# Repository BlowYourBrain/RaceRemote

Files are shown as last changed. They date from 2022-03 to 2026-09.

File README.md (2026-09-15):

# RaceRemote

Текущая сборка: [плата 0.3, отдельный общий провод XIAO и карта подключений](cad/xiao-return-h10/README.md).

Последняя примерка: [провода мотора и обнаруженный конфликт резерва клеммы с подвеской](cad/motor-harness/README.md).

Текущий вариант внутреннего питания: [CAD припаянной пары и крепления](cad/direct-logic-harness/README.md), включая ограничения прежней проводки.

Проект одинаковых радиоуправляемых машинок с управлением по Wi-Fi с телефона, сменными кузовами и опциональной камерой.

**Перед продолжением работы прочитайте [описание проекта и принятые решения](docs/project-brief.md).** Там собраны требования, имеющееся железо, результаты первичного аудита и вопросы, которые ещё предстоит решить.

**Ближайшие шаги к физической сборке:** [первый прототип](docs/first-prototype.md) — доступные устройства, недостающие данные и порядок радио/FPV, привода, механики и зарядки.

- [Стенд Android ↔ ESP32](docs/control-bench.md) — `vea.raceremote`, запуск и проверенные устройства.
- [Протокол Control v1](docs/control-v1.md) — команды, сессия и остановка.
- [Подготовка стенда привода](docs/drive-bench.md) — проект соединений TA6586, питание и проверка рулевого узла.
- [Контракты и их статус](docs/contracts.md) — согласованные требования и интерфейсы, которые предстоит определить.
- [Архитектура и known unknowns](docs/architecture-and-unknowns.md) — организация системы, открытые вопросы и способы их закрыть.
- [Кандидаты шасси](docs/chassis-candidates.md) — исходные проекты, ограничения и возможная адаптация под Wi-Fi.
- [Детали и цены](docs/parts.md) — предложения магазинов, количество на 1/4/6 машинок и незакрытые позиции.
- [Камера для FPV](docs/camera-candidates.md) — кандидаты и проверка задержки до выбора для серии.
- [Первый FPV-стенд](docs/fpv-bench.md) — состав, подключение и порядок измерений; предложение для покупки ещё подбирается.
- [USB-C: зарядка и прошивка](docs/usb-c-power.md) — отдельный удобный зарядный порт, ограничения для 2S и сервисный USB под кузовом.
- [Watchdog зарядного контроллера](hardware/charge-watchdog/README.md) — схема-кандидат и проверка удержания запрета при зависании MCU.
- [Зарядный MCU и согласование сигналов](hardware/charger-mcu/README.md) — CH32, аппаратный ARM/revoke/readback и доступ SWIO; схема без программы и монтажа.
- [Удерживаемая ошибка зарядного тока](hardware/charge-overcurrent/README.md) — INA300 и шунт, схема стенда и границы проверки.
- [Смена батареи и кузов](docs/battery-and-body.md) — три LW 601844HP, быстрое снятие кузова на магнитах и зарядка запасной батареи.
- [Правила работы агента](AGENTS.md) — обязательная фиксация ключевых моментов и контрактов по просьбе пользователя.

Репозитории:

- [RaceRemote](https://github.com/BlowYourBrain/RaceRemote) — Android-приложение и старые эксперименты с Arduino.
- [RC_CAR_ESP32](https://github.com/BlowYourBrain/RC_CAR_ESP32) — прошивка стенда ESP32 и старый эксперимент; приватный репозиторий.

Выбор серийных компонентов и электрическая схема пока не утверждены.

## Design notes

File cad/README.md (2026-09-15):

# Примерка батареи в zcar

**Для будущей примерки электроники:** [актуальный комплект из пяти отдельных объектов STL/3MF](current-fit-kit/README.md), включая держатель XIAO с окном питания и поддон с седлом проводов. Это геометрия без G-code; печать отложена.

**Актуальная сборка проводки при 0/+3 — [пара серво со съёмной вязкой](servo-lacing/viewer.html), [описание и ограничения](servo-lacing/README.md).** Включает плату H10 и отдельные провода мотора/XIAO. Реальные концы жгута, физическое удержание и силовой вход остаются открытыми. Более ранняя [компоновка 0.6](current-layout/README.md) содержит исследование регулировок; его результаты не распространяются на новую проводку. Старые сцены ниже — история.

15 сентября: [направляющие жгута 0.1 и обновлённая сборка](harness-guides/README.md). В поддон и прижим встроены два открытых седла под съёмную фиксацию проводов. С новыми деталями проверены начальная посадка, 76 положений снятия кузова, 25 положений упора, 28 положений прижима и непрерывный выход коробки батареи влево. Точки регулировки, физическая затяжка/печать и реальные провода остаются открытыми.

15 сентября: [съёмный держатель XIAO 0.1](xiao-mount/README.md) с опорой, прижимом и STL для примерки. Исправлена ошибка направления сервисного USB: по именованной STEP он выходит по +X, а прежний резерв 0.5 был направлен по −X. Новая сцена также меняет три трассы проводов и край поддона; старые регулировки/снятие кузова для неё ещё не квалифицированы.

15 сентября: [проверка обслуживания компоновки 0.5](packaging-service.md) учитывает новые платы и трассы проводов. В начальном положении геометрически свободны составное снятие кузова, снятие левого упора и выход батарейного макета влево с оставленным правым упором. Физические разъёмы батареи, пальцы и удержание ещё не проверены.

**15 сентября: текущая итерация — [детальная компоновка 0.5](packaging-v05/README.md) и [интерактивная сборка](packaging-v05/viewer.html).** Добавлены STEP SG90, подробный Waveshare -M, раздельные места плат, провода, зарядный USB и предложение выемок рамы. Прежние итерации ниже сохранены для сравнения; полной физически проверенной конструкции пока нет.

14 сентября: [компоновка бокового зарядного USB-C 0.2](usb-port-study.md) с [переключением закрытого порта и кабеля в 3D](usb-port-study-viewer.html) обновлена по [разведённой PCB KiCad](../hardware/usb-port/README.md). Основание, плата с отверстиями и площадки экспортированы; геометрия проверена. Фиксация накладки/жгута и изготовление ещё впереди.

Последние результаты: [регулируемые крепления 0.3](adjustable-layout.md) с [двумя ползунками в 3D](adjustable-layout-viewer.html) и [примерка конкретных кандидатов 0.4](candidate-fit.md) с [моделью XIAO из STEP](candidate-fit-viewer.html). В 0.4 выявлена неопределённость посадки SG90; полная CAD-модель машины всё ещё не завершена. Описание 0.2 ниже — предшествующая габаритная итерация.

**Полная конструкция RaceRemote ещё не закончена.** Текущий вариант — [компоновка под кузов 0.2](body-study.md) и [вращаемая модель](body-study-viewer.html): условный кузов 70×155×54 мм, исходная механика, батарейный узел и более низкие габаритные резервы электроники. Это предложенная форма, не подтверждённая посадка покупного Mini-Z. [Прежняя компоновка 0.1](assembly.md) высотой 62 мм без кузова сохранена для сравнения. Реальные платы/провода, крепления, окна камеры и магниты ещё не спроектированы полностью. Ниже сохранена документация батарейной примерки; изображения сечений не являются чертежами готовой машинки.

Следующая итерация — [держатель 0.2](battery-holder.md): опора, два съёмных торцевых упора, канавка и резерв эластичного ремешка. Подготовлены SCAD/STL, проверены коллизии и путь снятия. Это кандидат для физической примерки, не испытанное крепление; описание ниже сохраняет исходную компоновку 0.1.

2026-09-13, исследовательская компоновка 0.1. Размер батареи **49 × 18 × 15 мм** взят из карточки покупки, которую подтвердил пользователь; его аккумуляторы ещё не измерены. Это CAD-макет, не готовый держатель и не подтверждение физической совместимости.

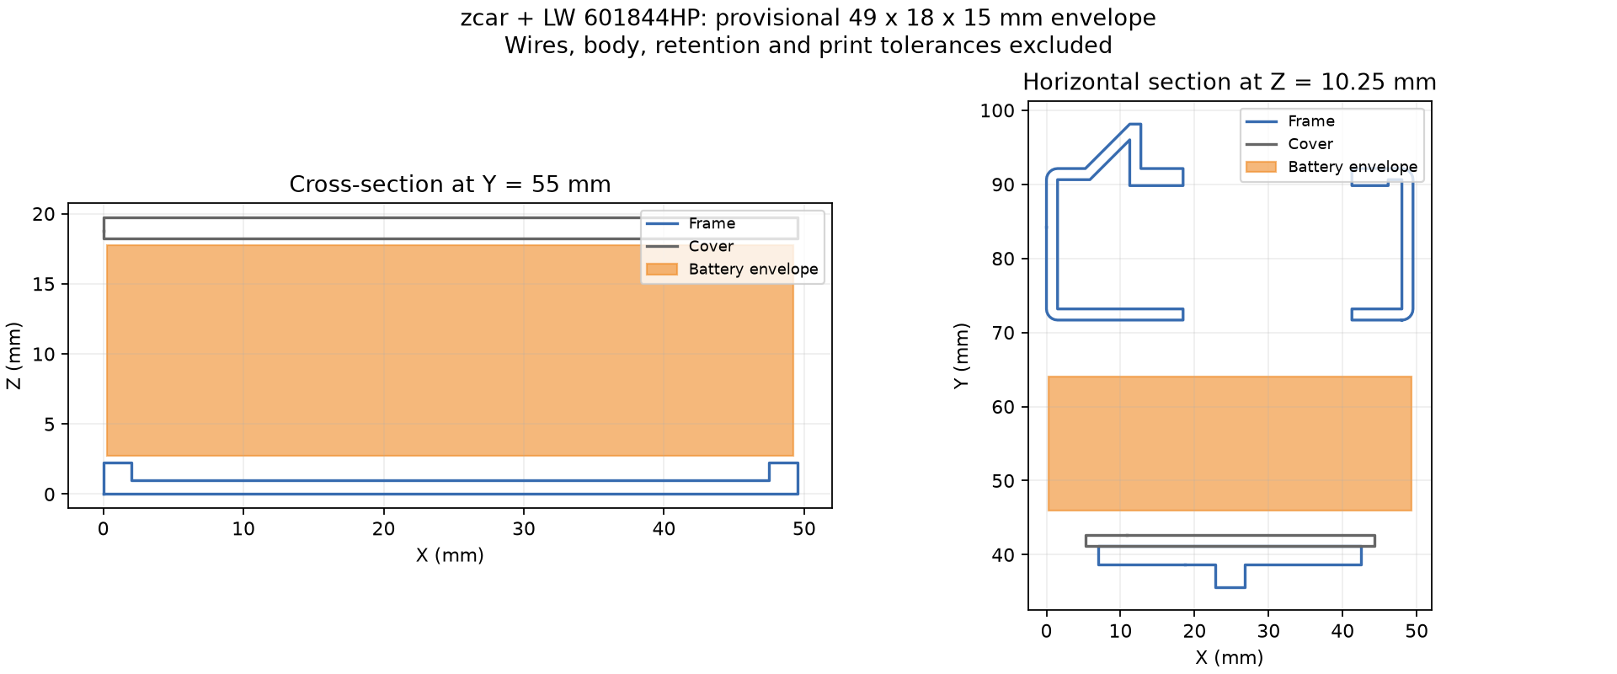
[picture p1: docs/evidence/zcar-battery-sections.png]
Сечения рамы, центральной детали и макета батареи


## Полученный результат

Макет располагается поперёк рамы. Оси: X — поперёк машины, Y — вдоль, Z — вверх; начало координат — минимум габаритов основной рамы. Центр макета `(24,75; 55; 10,25)` мм; занимаемый объём от `(0,25; 46; 2,75)` до `(49,25; 64; 17,75)` мм.

| Проверка | Результат в модели |
| --- | --- |
| Макет в выбранном положении | Пересечение с рамой и центральной деталью: 0 мм³; габариты остальных компонентов сборки не пересекаются с макетом |
| Прямое извлечение на 50 мм в сторону −X | Весь объём перемещения, включая промежуточные положения, свободен от этих деталей |
| Подъём макета на 1 мм | Пересечение с центральной деталью 428,0625 мм³; это также положительная контрольная проверка обнаружения коллизии |

В центральном сечении верх боковых выступов рамы находится на Z=2,25 мм, нижняя поверхность полки — на Z=18,25 мм. Макет оставляет **по 0,5 мм вертикального зазора** относительно этих поверхностей. По ширине его края находятся в 0,25 мм от внешних границ рамы; это **не зазор до кузова**. Размер 49 мм сам по себе не требует расширить раму на 4 мм относительно батареи из README автора.

Макет пока «висит» над дном отсека: для выбранной высоты нужна опора примерно 1,75 мм над центральным дном Z=1 мм. Её конструкция, крепление, мягкая прокладка и независимый фиксатор ещё не разработаны. Пустое место в CAD не означает, что незафиксированную батарею уже можно ставить на машинку.

Для следующей итерации предлагается снять кузов, освободить фиксатор и разъёмы, затем выдвинуть батарею вбок. Такой путь позволяет оставить центральную полку на месте. Доступ руками, провода, разъёмы, кузов, новые платы, камера и антенна в проверку **не включены**. Направление выхода проводов у реальных пакетов ещё нужно установить. Предложенный ранее доступ сверху после снятия кузова сохраняется как сценарий обслуживания; непосредственное извлечение вверх потребовало бы изменения полки.

## Файлы и воспроизведение

- [battery-layout.scad](battery-layout.scad) — редактируемая модель OpenSCAD. `part="layout"` показывает компоновку; `extraction_offset` от 0 до −50 мм показывает боковое извлечение. Для просмотра нужны сгенерированные ниже STL рамы и центральной детали.
- [battery-dummy.stl](battery-dummy.stl) — готовый геометрический макет 49 × 18 × 15 мм для возможной примерки. Это простой брусок без проводов/разъёмов; печать и физическая примерка не выполнялись. Его размер нужно обновить после измерения всех трёх батарей.
- [Числовой отчёт](../docs/evidence/zcar-battery-layout.json) — исходная ревизия, SHA-256, преобразования и объёмы пересечений.
- [Скрипт](../tools/layout_zcar_battery.py) — восстанавливает компоновку из зафиксированных STL, проверяет геометрию и создаёт сечения.

Из корня RaceRemote, если исходный клон уже подготовлен по [инструкции](../docs/chassis-candidates.md#проверка-файлов-cad):

```powershell
uv run --with-requirements tools/cad-requirements.txt python tools/layout_zcar_battery.py build/upstream/zcar
```

Результаты появятся в игнорируемом `build/cad-layout`: `frame.stl`, `cover.stl`, `battery.stl`, `report.json`, `sections.png`, `SOURCE.txt`, `UPSTREAM-LICENSE`. `battery.stl` сохраняет положение в сборке; опубликованный `cad/battery-dummy.stl` экспортирован из OpenSCAD с началом в нижнем углу для печати.

Проверенный экспорт в Windows PowerShell:

```powershell
& 'C:/Program Files/OpenSCAD/openscad.com' -o build/cad-layout/battery-dummy.stl -D 'part=\"battery_dummy\"' cad/battery-layout.scad
```

Экспорт OpenSCAD прошёл; получена замкнутая ориентированная сетка с габаритами ровно 49 × 18 × 15 мм. Это проверка файла, не точности принтера. В других оболочках экранирование аргумента `-D` может отличаться.

## Метод и ограничения

Источник геометрии — [alexyu132/zcar, ревизия 4b714e6](https://github.com/alexyu132/zcar/tree/4b714e63fa30ed2030a8a48ab15f1e4a5fa380c4). Для объёмных операций используются замкнутые детали `tray1.stl`, размещённые по сборочной модели. Центральная деталь повёрнута из печатного положения; рама перенесена без изменения формы. Основные поверхности совпадают с точностью менее 0,001 мм. У трёх вершин рамы расстояние до незамкнутой сборочной сетки больше: максимум 1,0353 мм на дальнем конце, вне батарейного отсека. Эти расхождения сохранены в отчёте, а не исправлены автоматически.

Для рамы и центральной детали рассчитаны булевы пересечения замкнутых тел. Для остальных частей исходной сборки проверены ограничивающие параллелепипеды: отсутствие их пересечений исключает пересечение самих поверхностей в проверенном объёме. Модель не содержит всех компонентов будущей машинки. Нулевой объём пересечения не заменяет расчёт допусков, жёсткости и проверку удержания.

Сечения содержат геометрию zcar; сопровождающая [GPL-3.0 из исходного репозитория](../docs/evidence/zcar-LICENSE.txt) сохранена вместе с ними. Сгенерированные сторонние STL остаются в `build` с атрибуцией и той же лицензией. Исходник `zcar.skp` не менялся.

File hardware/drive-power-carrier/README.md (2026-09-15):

# Общая плата привода и питания XIAO — предложение 0.3

**0.3, 15 сентября:** добавлена отдельная площадка H10 для общего провода XIAO; H5 остаётся силовым возвратом входного питания. Схема/PCB проходят ERC, DRC и parity: 26 позиций, 58 выводов, семь подмен цепей. Прежние 57 площадок и дорожки версии 0.2 сохранены, зоны меди пересчитаны. [Отчёт v03](../../docs/evidence/drive-power-carrier-v03/summary.json), [текущая проводка и карта площадок](../../cad/xiao-return-h10/README.md). Геометрическая проверка H10 и нового провода пройдена при 0/+3; ток/нагрев и физический монтаж не проверены. Ниже сведения о конструкции 0.2 остаются основанием; её отчёты исторические в `957e015`.

15 сентября 2026. Контракт **DRIVE-POWER-CARRIER-01 v0.2**. Это отдельный кандидат объединения [носителя TA6586](../motor-carrier/README.md) и [XIAO-LOGIC-01 v0.2](../xiao-logic-power/README.md). В 0.2 исправлены [площадки MAX40200 и резерв его корпуса](max40200-package.md); уведомление 2571C оказалось изменением транспортной упаковки. Исходные схемы сохранены. Изготовления, монтажа и физических испытаний ещё нет.

[Схема PDF](schematic.pdf) · [редактируемая схема](drive-power-carrier.kicad_sch) · [PCB KiCad](drive-power-carrier.kicad_pcb) · [верх](top.svg) · [низ, зеркальный вид](bottom.svg) · [BOM](bom.csv) · [все выводы](connections.csv) · [3D в машинке](../../cad/drive-power-carrier/viewer.html).

Размер PCB остался **30 × 18 × 1,6 мм**. Сохранились места всех 14 прежних позиций и геометрия их 27 площадок. Новые U2/U3, делитель и конденсаторы находятся снизу; нагрузочный R7 — сверху. Два прежних отрезка VM заменены обходом четырёх тепловых переходов U2. Остальные прежние дорожки сохранены. Вместо отдельной платы питания получилась одна плата с 25 позициями: 16 покупных компонентов и девять встроенных площадок для проводов.

| Площадка | Цепь и назначение |
|---|---|
| H1 / H2 | CMD_FI / CMD_BI: команды TA6586 через прежние резисторы |
| H3 / H5 | DRIVE_GND: общий провод привода и логики, не произвольная земля зарядника |
| H4 | VM: отдельно квалифицируемое питание мотора |
| H6 / H7 | FO / BO: выводы мотора |
| H8, новая | WAVE_5V: вход от Waveshare, условный расчётный диапазон 4,75…5,25 В |
| H9, новая | XIAO_BAT: выход через MAX40200 к BAT0 XIAO; не к выводу 5V/VBUS |
| H10, добавлена в 0.3 | DRIVE_GND: отдельная посадка провода GND0 XIAO; H5 освобождена для силового возврата |

Участники питания: Waveshare → U2 TPS73701DRBR → U3 MAX40200AUK+T → BAT0 XIAO. Общий провод XIAO/Waveshare приходит к DRIVE_GND. VM, WAVE_5V и XIAO_BAT — разные цепи. К новой плате не добавлен провод штатного USB VBUS. Сырой аккумулятор 2S нельзя подключать к H8/H9; объединение минусов батареи, защиты и USB зарядки требует отдельной согласованной схемы. Эта плата не заряжает LW и не заменяет его защиту.

Схема логики электрически повторяет v0.2 с перенумерацией: прежние U1/U2 → U2/U3; R1…R3 → R5…R7; C1…C4 → C3…C6; J1/J3 → H8/H9. Земляные J2/J5 заменены существующими H3/H5. U2 выдаёт номинально 3,997 В; R7=360 Ом обеспечивает предварительную нагрузку до обратного блокиратора. Для C4 требуется фактическая ёмкость ≥1 мкФ, для C5/C6 ≥0,33 мкФ каждого, полная ёмкость на выходе U3 ≤100 мкФ. Конкретные MLCC и их зависимость от напряжения ещё не выбраны.

При исчезновении питания логики аппаратная остановка здесь не доказана: сохраняются резисторы на входах TA6586 и программные правила остановки, но последовательность спадания шин, USB-переходы и ток мотора требуют стенда. MAX40200 имеет внутреннюю обратную блокировку; её реальные переходы и отказы платы пока не проверены.

Проверки KiCad 10.0.6: **ERC=0, DRC=0, несоединённых цепей=0, расхождений схемы и платы=0**. Независимый список сверяет 57 выводов, включая четыре NC, и 12 рабочих цепей; шесть намеренных подмен цепей обнаружены. Координаты CAD сверены с площадками и центрами новых компонентов PCB; размеры/шаг площадок U3 — с прочитанным чертежом. [Отчёт и хеши](../../docs/evidence/drive-power-carrier-v02/summary.json), [DRC с перечнем стандартно отключённых проверок](../../docs/evidence/drive-power-carrier-v02/drc.json). Это проверка проекта при выбранных правилах, не подтверждение его допустимого тока. Отчёты v01 относятся к прежней геометрии `c041b2b`.

Разводка предлагает минимальный зазор/ширину 0,15 мм, силовые дорожки прежнего носителя — 1,2 мм, новые основные линии питания — 0,4…0,6 мм. Четыре перехода под тепловой площадкой U2 имеют отверстие 0,3 мм и диаметр меди 0,6 мм. Изготовитель, толщина меди, обработка переходов, маска/паста и ручной монтаж не согласованы. Gerber для заказа не выпущен.

Открытые вопросы перед изготовлением:

- U2 DRB: посадка основана на TI Rev W, стр. 47–48; тепловая площадка обязательна. Заполнение/закрытие переходов и объём припоя нужно согласовать, иначе припой может уйти в отверстия.
- U3: корпус сверён с официальным 21-0057 K, площадки — с копией Maxim 90-0174 B. Актуальность редакции рисунка площадок у ADI и посадка реального компонента ещё не подтверждены. PIN2571C касается только транспортной упаковки.
- Тепло двух микросхем рядом с моторным драйвером. Прежний условный расчёт даёт около 0,513 Вт на проходном элементе U2 при 0,5 А и до 0,850 Вт в выбранном углу при 0,6 А, без собственного тока и переходных процессов. Сам факт наличия меди/переходов не доказывает допустимую температуру.
- Стабильность питания при работе камеры, пусках мотора/серво и подключении USB; реальные токи и допустимая нагрузка дорожек.
- Новые провода H8/H9, разгрузка пайки, установка/снятие платы и остальные положения регулировки.

Источники геометрии: [TPS737, TI Rev W](https://www.ti.com/lit/ds/symlink/tps737.pdf), [MAX40200, ADI Rev 4](https://www.analog.com/media/en/technical-documentation/data-sheets/max40200.pdf); исходные электрические расчёты и ограничения переноса падения напряжения SOT23 с 3,3 В на около 4 В — в [XIAO-LOGIC-01 v0.2](../xiao-logic-power/README.md). Новых цен и заказов этот BOM не подтверждает; имеющиеся ценовые наблюдения остаются в [таблице деталей](../../docs/parts.md).

Воспроизведение из корня репозитория, локальным Python KiCad:

```powershell
& build/tooling/kicad-10.0.6/bin/python.exe tools/build_drive_power_carrier.py
& build/tooling/kicad-10.0.6/bin/python.exe tools/verify_drive_power_carrier.py
uv run --with-requirements tools/cad-candidate-requirements.txt python tools/check_drive_power_fit.py
uv run --with-requirements tools/cad-candidate-requirements.txt python tools/build_drive_power_view.py
```

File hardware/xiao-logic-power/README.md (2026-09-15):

# Питание XIAO от общей линии 5 В, предложение 0.2

15 сентября 2026. **XIAO-LOGIC-01 v0.2** заменяет LM66100 на MAX40200AUK+T: обратное напряжение на ключе отслеживает сам IC, внешний провод обнаружения USB больше не нужен. Обновлены [KiCad](xiao-logic-power.kicad_sch), [PDF](schematic.pdf), [соединения](connections.csv) и [BOM](bom.csv). PCB, тепловая/переходная квалификация и монтаж ещё отсутствуют.

## Соединение с машинкой

```mermaid
flowchart LR
    W[Waveshare: 5 В] --> L[TPS73701: около 4 В]
    W --> S[Серво: отдельная силовая ветвь]
    L --> K[MAX40200: автоматическая обратная блокировка]
    K --> B[XIAO BAT0]
    USB[Штатный USB XIAO] --> X[Штатная схема питания XIAO]
    B --> X
```

| Вывод | Соединение | Ограничение |
| --- | --- | --- |
| J1 WAVE_5V | Выход Waveshare в режиме 5 В | Расчёт требует измеренных 4,75…5,25 В; это не гарантия модуля |
| J2 DRIVE_GND | Возврат питания Waveshare | Силовой ток серво/мотора не вести через XIAO |
| J3 XIAO_BAT | Положительная площадка BAT0 XIAO | Только выход узла; сырые 2S сюда не подключаются |
| J5 DRIVE_GND | GND XIAO | Общая опора с J2; связь с сырой батареей/землёй зарядки здесь не назначена |

**J4 удалён, его номер не переиспользован.** Боковой 5V XIAO и отдельный зарядный USB к этой схеме не подключаются. EN U2 соединён с его VDD локальной дорожкой. Четыре J — логические интерфейсы, не покупные разъёмы.

На [схеме Seeed, лист 4](https://files.seeedstudio.com/wiki/SeeedStudio-XIAO-ESP32S3/new-res/202003753_XIAO%20ESP32S3%20Sense_v1.5_SCH_260226.pdf.pdf) боковой 5V соединён с USB VBUS, а BAT0 — со штатным зарядником U4. Прямые внешние 5 В на боковом контакте не развязывают компьютер. Реальная ревизия заказанной платы неизвестна. Этот узел не заряжает LW; отдельная [2S USB-C зарядка](../../docs/usb-c-power.md) остаётся незавершённой.

## Выбор ключа

[MAX40200 Rev 4, февраль 2023, стр. 2–3, 8–9](https://www.analog.com/media/en/technical-documentation/data-sheets/max40200.pdf): SOT23-5 имеет VDD=1, GND=2, EN=3, NC=4, OUT=5. Обратная блокировка предусмотрена внутри; внешний USB-сигнал не нужен. Диапазон питания — 1,5…5,5 В.

Для **SOT23**, при паспортной точке VDD=3,3 В, падение при 0,5 А — 97 мВ типично / 175 мВ максимально. Рекламные 43 мВ относятся к WLP. Точка 1 А измерялась импульсно; она не устанавливает непрерывный ток нашей PCB. Типовые времена EN не задают гарантированный обратный импульс при переключении источников.

C3/C4 увеличены до **1 мкФ X7R/10 В**: каждый должен сохранять ≥0,33 мкФ, а полная выходная ёмкость с XIAO — оставаться ≤100 мкФ. Конкретные MPN и вся нагрузка ещё не проверены.

[TPS737 Rev W, §6.3.3–6.3.4](https://www.ti.com/lit/ds/symlink/tps737.pdf) не гарантирует обратную блокировку при EN=IN; регулируемая версия имеет путь через FB. Поэтому U2 необходим. Медленный запуск U1 может дать выброс; новая схема этого не устраняет. Номер 9 у U1 в нашем символе обозначает тепловую площадку GND, а не дополнительную ножку корпуса.

## Расчёт и оставшиеся ограничения

[Скрипт](../../tools/calculate_xiao_logic_power.py) и [отчёт 0.2](../../docs/evidence/xiao-logic-power-v02/dc-calculation.json) проверяют 320 сочетаний допусков R1/R2=23,2/10 кОм 0,1%, ±3% U1 и дополнительного знакопеременного запаса IFB. Это условная DC-оценка.

| Результат модели | Значение |
| --- | --- |
| Выход U1 | Номинально 3,997 В; оценка 3,858…4,137 В |
| Запас сверх 0,5 В между IN и OUT U1 | Минимум 0,113 В при принятом входном диапазоне |
| Преднагрузка R3=360 Ом 1% перед U2 | 10,61…11,61 мА; до 0,048 Вт |
| Потери U1 при номинальных 5 В и нагрузке 0,5 А | 0,513 Вт |
| Максимум потерь U1 среди режимов до 0,6 А | 0,850 Вт, без собственного потребления U1/U2 |
| Нижняя оценка BAT при 0,5 А, если падение U2 ≤175 мВ | 3,683 В до потерь проводов/Q1 |
| Потери U2 при 0,5 А при том же допущении | До 0,0875 Вт |

Перенос предела падения со входа 3,3 В на наши около 4 В — **проектное допущение**. Для 0,6 А точный предел не назначен; интерполяция не выдаётся за гарантию. 0,5/0,6 А — исследуемые нагрузки, не измеренное потребление камеры. При общей линии 4,5 В условие запаса U1 уже нарушено. R3 оставлен перед U2 для нагрузки U1 ≥10 мА; C2 предложен 4,7 мкФ с фактической ёмкостью ≥1 мкФ.

| Состояние | Ожидаемое поведение / неизвестность |
| --- | --- |
| Waveshare включён, USB нет | U2 проводит к BAT0; запуск камеры и просадка не проверены |
| Штатный USB подключён | При BAT0 выше выхода U1 ключ должен блокировать обратный путь автоматически |
| Waveshare выключен, USB подключён | Внешний провод для блокировки не нужен; переход к малому VIN и утечки не измерены |
| Оба источника выключены | Разряд конденсаторов; нулевой обратный ток через U1 не заявлен |
| Обрыв прежнего USB-сигнала | Такого соединения в 0.2 нет; это не защита от любых обрывов/отказов IC |
| Переключение USB, дребезг, пуск серво | Обратный импульс, выброс U1 и непрерывность питания XIAO неизвестны |

Теплоотвод, собственные токи IC, пульсации, Q1/провода и размещение PCB ещё требуют работы. Путь LW→защита→выключатель→Waveshare не квалифицирован. Мультиметр не проверит короткие выбросы; подходящего прибора пока нет. Отдельный buck с блокирующим диодом остаётся резервом. Печать отложена.

## Закупка и доказательства

[MAX40200AUK+T в ЧИП и ДИП](https://www.chipdip.ru/product/max40200auk-t-mikroshema-idealnyy-diod-s-sverhnizkim-maxim-9000587524): 15 сентября **50 ₽ от 1 шт.**, 97 шт. на складе Москвы, ориентировочный бесплатный самовывоз в Чебоксарах 18 сентября. Только этот IC для 1/4/6 машин — 50/200/300 ₽, не стоимость всей платы. Заголовок магазина переносит падение WLP на SOT23; аналоги TPMAX не признаны эквивалентными. Покупок нет.

На [странице ADI](https://www.analog.com/en/products/max40200.html) указан PCN 2571C от 20 апреля 2026 для AUK. Содержание пока не прочитано; влияние на корпус/параметры не установлено. Проверить перед фиксацией закупки/посадочного места.

[Отчёт 0.2](../../docs/evidence/xiao-logic-power-v02/summary.json): 13 позиций, 32 вывода включая четыре NC, пять рабочих цепей; экспорт KiCad и CSV сверены с независимой таблицей. **ERC=0 без нового подавления**: прежнее замечание ST→GND исчезло вместе с LM66100. PDF просмотрен. Нет PCB/DRC, SPICE, пайки или физических испытаний. Сохранены [источники](../../docs/evidence/xiao-logic-power-v02/sources.json) и [предложение магазина](../../docs/evidence/xiao-logic-power-v02/shop.json).

Повторение: `python tools/build_xiao_logic_power.py`, затем `python tools/verify_xiao_logic_power.py` из корня, с имеющимся KiCad CLI в `build/tooling/kicad-10.0.6/bin`. Схема 0.1 со старым проводом/LM66100 находится в коммите `11380ef`; отчёты `xiao-logic-power-v01` исторические и не описывают текущие файлы.

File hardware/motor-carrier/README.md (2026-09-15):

# Носитель TA6586, кандидат 0.1

Подготовлен [кандидат съёмного держателя](../../cad/motor-carrier-mount/README.md) с STL поддона, прижима и макета PCB. Геометрическая проверка крепления не заменяет физическую примерку и квалификацию платы.

15 сентября 2026. Подготовлены схема и разведённая двухслойная плата **30 × 18 × 1,6 мм** для имеющегося TA6586. Это предложение для проверки; плата не изготовлена, допустимый ток не установлен, выпуск в производство не выполнен.

[Схема PDF](schematic.pdf) · [KiCad PCB](motor-carrier.kicad_pcb) · [верх](top.svg) · [низ, зеркальный вид](bottom.svg) · [BOM](bom.csv) · [3D-примерка](../../cad/motor-carrier/README.md).

## Состав и интерфейс MOTOR-CARRIER-01 v0.1

Статус: предложение агента. 14 позиций схемы включают семь площадок для пайки проводов; это не семь покупных разъёмов. U1 берётся из имеющихся трёх TA6586. Предложены R1/R2 100 Ом 1%, R3/R4 10 кОм 1%, C1 100 нФ/25 В и C2 470 мкФ/16 В. Пассивные детали не заказаны; цены/наличие не проверены.

| Площадка | Цепь | Назначение |
| --- | --- | --- |
| H1 | CMD_FI | Вход команды переднего направления через R1 к U1.2 |
| H2 | CMD_BI | Вход обратного направления через R2 к U1.1 |
| H3 | DRIVE_GND | Опорная земля управления |
| H4 | VM | Питание драйвера от отдельно проверенного силового пути |
| H5 | DRIVE_GND | Силовой возврат питания; не через провод MCU |
| H6 | FO | Объединены U1.5 и U1.6, один вывод мотора |
| H7 | BO | Объединены U1.7 и U1.8, второй вывод мотора |

Подтяжки R3/R4 расположены после последовательных резисторов, на стороне IC. По [документу производителя TA6586](https://static.chipdip.ru/lib/923/DOC012923012.pdf), FI=BI=0 размыкает выходы; это выбег, не доказательство тормозного пути. Внешний обрыв команды предполагает LOW через подтяжку, но переходы питания/обрыв земли/реальные уровни ещё не проверены. Таблица входных уровней дана при VCC=6 В; совместимость 3,3 В во всём рабочем диапазоне и частота PWM остаются открыты.

VM/DRIVE_GND не определяют соединение с сырыми выводами LW, землёй USB или защитой батареи. На носителе нет зарядника, BMS, предохранителя или независимого ограничения стендового тока. Он не завершает POWER-01/CHARGE-01. Маркировка «7 А» не является установленным током этой платы: производитель требует теплоотводящую медь у выводов 5–8, а температура/толщина меди/токи мотора пока неизвестны.

## Геометрия и проверка

- Собственные символы/посадочные места; DIP8 шаг 2,54 мм, ряды 7,62 мм, без панельки. Формовку ножек сверить с образцом. Сигнальные дорожки 0,3 мм, основные силовые 1,2 мм; зоны FO/BO и земли. Эти размеры не заменяют расчёт/испытание токов.
- C1 находится снизу. Его высота, подрезанные ножки и зазор под платой зарезервированы на 0,9 мм; крепление ещё нужно разработать.
- C2: геометрический ориентир **Rubycon 16ZLH470MEFC8X11.5**, не утверждённая покупка. [Официальный ZLH PDF](https://www.rubycon.co.jp/wp-content/uploads/catalog-aluminum/ZLH.pdf), таблица размеров: номинально Ø8 × 11,5 мм, максимально Ø8,5 × 13 мм, шаг 3,5 мм. Предложен зазор до платы 0,5 мм. Общая высота с PCB и нижним резервом — 16 мм.
- KiCad 10.0.6: ERC=0, DRC=0, разрывов=0, расхождений со схемой=0. Независимо сверены 27 выводов/8 цепей; четыре изменения таблицы выводов обнаружены проверкой. Стандартные отключённые категории DRC перечислены в отчёте, дополнительных подавлений не добавлялось.
- [Отчёт и хеши](../../docs/evidence/motor-carrier-v01/summary.json), [DRC](../../docs/evidence/motor-carrier-v01/drc.json), [ERC](../../docs/evidence/motor-carrier-v01/erc.json). Это статические проверки, без пайки и электрических испытаний.

Генерация из корня репозитория: Python из `build/tooling/kicad-10.0.6/bin` запускает `tools/build_motor_carrier_schematic.py`, затем `tools/build_motor_carrier_pcb.py`, затем `tools/verify_motor_carrier.py`. PDF/SVG экспортируются `kicad-cli`; CAD — отдельным скриптом, указанным в его README. Перед изготовлением нужны крепление, вывод проводов/разгрузка натяжения, проверка закупленных корпусов, внешнего питания и достаточности теплоотвода.

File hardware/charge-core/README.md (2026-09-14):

# Зарядный преобразователь BQ25886, предложение 0.2

Для проработки A добавлен [батарейный балансировщик PACK-BAL-01 v0.1](../pack-balancer/README.md).
Его BAT_RAW_N находится до низкобоковой защиты; это не готовое прямое
соединение с CHG_GND. BQ29209 даёт только малую балансировку/вторичный OVP,
нормальное ограничение напряжения каждой ячейки и полный узел остаются открытыми.

Добавлена [схема USB-входа](../usb-input-gate/README.md), USB-INPUT-GATE-01 v0.2: TPS25200 и независимое питание логики TPS70933, AUX — выход 3,3 В. ERC/12 выводов/шесть намеренных ошибок проверены; распознавание источника и обработка просадки ещё открыты. Условный clamp до 5,55 В не подтверждает прежний диапазон CHG_VBUS до 5,5 В и не ограничивает все выбросы; прямое объединение схем пока не принято.

14 сентября 2026. Подготовлена **электрическая схема основного преобразователя** варианта A. Это часть будущего встроенного зарядника, а не готовый зарядный модуль для LW. PCB, защита/балансировка ячеек, определение USB-источника и монтаж ещё не выполнены. Выбор BQ25886 для серии не утверждён; [сравнение A/B](../../docs/charge-node-comparison.md) остаётся актуальным.

[Проект KiCad](charge-core.kicad_pro) · [Исходная схема](charge-core.kicad_sch) · [PDF](schematic.pdf) · [BOM для подбора деталей](bom.csv) · [ERC](../../docs/evidence/charge-core-erc.json) · [Проверки и расчёты](../../docs/evidence/charge-core-verification.json)

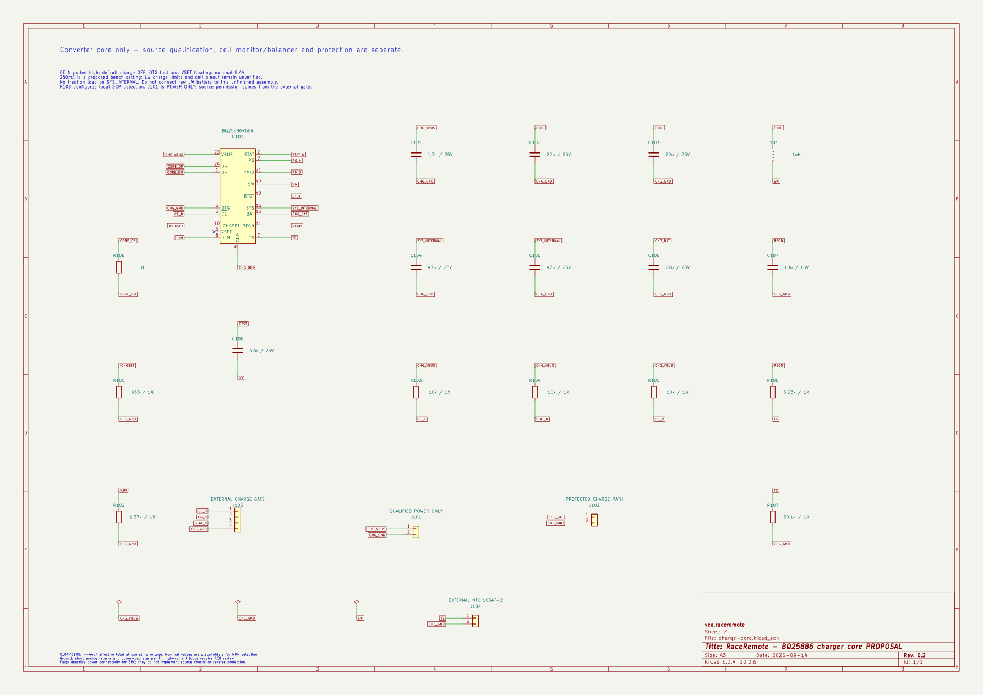
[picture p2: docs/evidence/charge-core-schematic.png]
Схема преобразователя


## Что спроектировано

U101 повышает входные 5 В для заряда 2S. В схеме 22 позиции: микросхема, дроссель, восемь конденсаторов, восемь резисторов и четыре логических интерфейса. Разъёмы, конкретные пассивные компоненты и их посадочные места ещё выбрать; строки BOM не означают наличие готовых деталей. QFN с нижней тепловой площадкой требует подходящего монтажа. 14 сентября пользователь подтвердил наличие паяльного фена; нагревательной плиты нет. Монтаж феном рассматривается для первого образца, но посадочное место, нанесение пасты, режим пайки и проверка соединений ещё не определены.

Основание: [TI SLUSD88A Rev. A, июнь 2019](https://www.ti.com/lit/gpn/bq25886), разделы 6, 7.5, 8.3.7 и 9.2; [схема EVM SLUUC11, февраль 2019](https://www.ti.com/lit/pdf/SLUUC11), стр. 12. Символы/посадочное место — [происхождение и лицензия](NOTICE.md).

| Цепь | Предложение и ограничение |
| --- | --- |
| ICHGSET, R101 | 953 Ом ±1%, номинально около 250 мА. Это настройка для проработки стенда, **не подтверждённый зарядный ток LW**. Прежние 300 мА были расчётным ориентиром, не требованием пользователя |
| ILIM, R102 | 1,37 кОм ±1%, номинально около 810 мА по входу. Не заменяет определение допустимого тока USB и учёт разброса/потребления остальных цепей |
| VSET | Оставлен свободным: номинально 8,4 В на сборке. Это не контроль напряжения каждой ячейки |
| CE_N, R103 | Подтяжка 10 кОм к CHG_VBUS: при свободном внешнем входе заряд запрещён. Разрешение — внешним открытым стоком; его логика ещё не создана |
| OTG | Постоянно соединён с CHG_GND; выдача питания на USB в этой схеме не используется |
| TS | 5,23 кОм от REGN, 30,1 кОм к земле и внешний термистор 103AT-2 у батареи. Постоянного резистора вместо датчика нет |
| SYS_INTERNAL | Только внутренний узел с C104/C105. **CE_N не выключает SYS**; тяга должна иметь отдельное отключение |
| C108 | 47 нФ между BTST и SW; соединение второго вывода с землёй было бы ошибкой |
| R108 | 0 Ом между CORE_DP и CORE_DM, только локальная настройка детектора BQ25886; внешние USB D+/D− сюда не подключаются |

При 250 мА точность в таблице TI составляет ±25% для указанных там напряжений 6,2/7,6 В и температуры кристалла 0…85 °C. С добавлением ±1% R101 арифметическая оценка — примерно 186…316 мА; это **не гарантированный предел во всём цикле**. Завершение номинально около 25 мА, предварительный заряд ограничен снизу типовыми 30 мА; при очень низком напряжении сборки предусмотрен отдельный режим около 100 мА. Автоматическое восстановление глубоко разряженной LW не разрешено.

Номиналы конденсаторов в BOM предварительные. До разводки нужны кривые ёмкости под постоянным напряжением и допуски: C104+C105 должны обеспечить не менее 44 мкФ эффективной ёмкости, C106 — 10 мкФ, C107 — 4,7 мкФ. Для L101 проверить насыщение, пульсации и потери. Номинальная надпись на корпусе не закрывает эти проверки.

## CHARGE-CORE-01 — границы интерфейса

Уточнён [USB-вход](../../docs/usb-source-qualification.md): ILIM не поддерживает уставку ниже 500 мА, а табличный верх при настройке 500 мА достигает 553 мА в указанных TI условиях. PG не выводит класс источника, CE не обесточивает SYS. Для неопределённого USB-порта нужен отдельный силовой запрет/лимит; номинал R102 сохранён. В v0.2 изменены только локальная настройка детектора и интерфейс J101, как описано ниже.

Статус: предложение v0.2; единицы — В, А, Ом. Участники: подготовленный USB-вход ↔ преобразователь ↔ отдельно проектируемый защищённый зарядный путь. **Это не распиновка имеющихся разъёмов батареи.**

| Интерфейс | Контакты по порядку | Условие подключения |
| --- | --- | --- |
| J101 | 1 CHG_VBUS; 2 CHG_GND | В v0.2 только питание от уже проверенного/защищённого источника; цель 5 В, предлагаемый диапазон 4,3…5,5 В. Внешних DP/DM больше нет; старый четырёхконтактный интерфейс заменён |
| J102 | 1 CHG_BAT; 2 CHG_GND | Через ещё не разработанный защищённый путь. Не подключать напрямую к непроверенной LW; MID/B−/P− здесь не назначаются |
| J103 | 1 CE_N; 2 PG_N; 3 STAT_N; 4 CHG_GND | Открытый сток разрешения и статус. Подтяжки к CHG_VBUS; **не подключать напрямую к GPIO 3,3 В**. PG не подтверждает исправность ячеек или разрешённый ток источника |
| J104 | 1 TS; 2 CHG_GND | Два провода термистора, размещённого у батареи; электрический и тепловой контакт проверить |

Обрыв управляющего провода оставляет CE_N высоким при исправной подтяжке и входном питании. Замыкание CE_N на землю не защищено этим резистором: внешняя логика/силовой путь должны учитывать отказ. В резистивной модели обрыв NTC даёт TS/REGN ≥0,849 при допусках ±1%, замыкание — 0; оба состояния вне рабочего окна TI. Это расчёт статических состояний, не испытание платы.

До соединения с пассивным USB-портом нужны ограничение/защита входа и его пускового тока. Допустимые 20 В на VBUS самой микросхемы **не распространяются на всю схему**: подтянутые CE/STAT/PG рассчитаны на меньшие напряжения. Отдельно проверить общий провод обоих USB-портов и отсутствие обхода батарейной защиты через B−/MID/сервисный USB.

В Rev. A строка NC=1 на стр. 5 расходится с D−=1 на стр. 4 и EVM. Использован D−=1; [TI прямо подтвердил, что строка NC ошибочна](https://e2e.ti.com/support/power-management-group/power-management/f/power-management-forum/823034/bq25886-standalone-2-li-ion-battery-charging-through-usb). Для тёплого/холодного режима таблица и раздел 8.3.7.4 называют разные коэффициенты тока/напряжения. Точный JEITA-профиль и температурный диапазон LW остаются проверками стенда.

## Локальная настройка DCP, без подключения к внешним USB-линиям

В [ответе инженера TI](https://e2e.ti.com/support/power-management-group/power-management/f/power-management-forum/823034/bq25886-standalone-2-li-ion-battery-charging-through-usb) разрешено соединить D+/D− BQ25886 между собой для выбора внутреннего режима DCP и ограничивать ток через ILIM. Поэтому в v0.2 добавлен R108=0 Ом, а J101 сокращён до двух контактов. CORE_DP соединён только с U101.24/R108.1, CORE_DM — с U101.1/R108.2. Переключатель между внутренним и внешним детектором больше не требуется для этой схемы.

Это **не распознавание реального зарядного блока**: локальный режим DCP не разрешает брать 3 А от кабеля. Источник отдельно проверяет будущий CC/BC-узел, прежде чем включить входной ключ. R102 сохраняет прежний номинальный ориентир 810 мА, действуют также внутренние ограничения/ICO; внешний TPS25200 и его разрешение остаются обязательными участниками. Согласование напряжений входа ещё не закрыто.

Внешние D+/D− остаются только на стороне USB-детектора. Если им станет BQ24392, его DP_HOST/DM_HOST не нужно проводить в зарядное ядро; тип источника должен передаваться в логике разрешения. BQ24392 пока не выбран: он не различает DCP и некоторые более слабые legacy-адаптеры своими выходами, поэтому HIGH на CHG_DET нельзя превращать прямо в разрешение ≥1,5 А. Подробности в [USB-SOURCE-01](../../docs/usb-source-qualification.md).

Ожидаемое последствие обрыва R108 — локальное распознавание может назначить малый входной ток вместо DCP; это не проверено на физическом BQ25886. Потребуются наблюдение запуска/ICO и проверка заданного тока с эквивалентом нагрузки после реализации остальной схемы.

## Проверено и что дальше

KiCad 10.0.6 ERC: 0 замечаний. По netlist сверены 25 выводов U101, пассивные цепи, четыре интерфейса и отсутствие внешних участников на CORE_DP/CORE_DM. Обнаружены четыре намеренные ошибки: C108 на землю вместо SW, потеря подтяжки CE, зарядный выход на входной VBUS и возврат R108 на землю. PDF и PNG обновлены и осмотрены. Это подтверждает соединения схемы, **не моделирует процесс заряда**. PCB/DRC и физической зарядки ещё нет.

```powershell
& build/tooling/kicad-10.0.6/bin/python.exe tools/build_charge_core.py
& build/tooling/kicad-10.0.6/bin/python.exe tools/verify_charge_core.py
uv run --with pymupdf python -c "import pymupdf; d=pymupdf.open('hardware/charge-core/schematic.pdf'); d[0].get_pixmap(matrix=pymupdf.Matrix(1.5,1.5)).save('docs/evidence/charge-core-schematic.png')"
```

Следующая необходимая часть — контроль обеих ячеек/балансировка и силовая защита со сменой батареи без активации USB; затем внешний запрет заряда и USB-вход. Выбор конкретных пассивных элементов, полная цена и компоновка следуют из полной схемы. Модель LW, её разъёмы, состояние и зарядные пределы требуют физических данных; ответ на ранее заданный вопрос о измерениях пока не получен. До проверки на имитаторе батареи подключение реальных аккумуляторов не является следующим действием.

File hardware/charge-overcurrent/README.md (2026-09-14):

# Удерживаемая ошибка зарядного тока

14 сентября 2026. **CHARGE-OC-01 v0.2 — схема-кандидат для стенда.**
Есть INA300, резистор порога и шунт. Нет общей PCB, окончательного включения
в зарядник, сборки и измеренного отключения тока. Номинальные 348 мА не
являются подтверждённым допустимым режимом аккумулятора LW.

[PDF](charge-overcurrent.pdf) · [KiCad](charge-overcurrent.kicad_pro) ·
[BOM](bom.csv) · [Проверки](../../docs/evidence/charge-overcurrent-verification.json) ·
[Порог и температурные оценки](../../docs/evidence/charge-current-guard.json)

## Схема и восстановление

U701 INA300AIDSQR питается от AUX. ENABLE и LATCH соединены с AUX аппаратно;
MCU не может выключить детектор или очистить ошибку через эти контакты.
DELAY соединён с землёй, HYS оставлен свободным. EP назначен локальный
логический номер 11 и соединён с землёй. R701=1,74 кОм задаёт порог.
ALERT идёт на FAULT_BUS_N: J703 совпадает с J402 листа permit.
Подтяжка только одна — существующий R401, новых 10 кОм на этом листе нет.

[TI SBOS613C, июнь 2021](https://www.ti.com/lit/ds/symlink/ina300.pdf),
таблица 5-1 и §§6.5–6.6, 7.3–7.4: в режиме LATCH HIGH ошибка остаётся
после снижения тока. Документированная очистка — LATCH LOW не менее 20 мкс
при исчезнувшем превышении. Режим 50 мкс требует пяти последовательных
окон сравнения по 10 мкс. ALERT — открытый сток; VOL≤0,4 В задан при 3 мА,
утечка — до 1 мкА при VOH=3,3 В. Для старта приведено номинальное 1 мс;
это не гарантированное время готовности всего зарядного узла.

В этом варианте программной очистки нет. Предложение для готового изделия —
после токовой ошибки требовать отключения USB и новой процедуры запуска.
**Сброс ошибки от такого цикла ещё не доказан:** нужны измерение падения AUX,
отсутствие подпитки от батареи/отладчика, проверка ALERT после включения и
удержание общего запрета на всём переходе. Фиксированное ожидание «1 мс»
или перезапуск только программы MCU не заменяют этой проверки. Если после
старта ALERT остаётся LOW, ARM не должен разрешать заряд. Не подключать
перемычку LATCH на землю в работающей схеме: он напрямую соединён с AUX.

## Шунт и граница силового подключения

R702 **Yageo RL2512FK-070R1L**: 0,1 Ом ±1%, 1 Вт при 70 °C, TCR ±600 ppm/°C;
габарит 6,35±0,1 × 3,2±0,15 × 0,55±0,1 мм. Это двухвыводный резистор:
измерительные дорожки нужно подвести отдельно к контактам резистора,
не включать в измерение падение на силовой дорожке/проводе.
[Спецификация Yageo, генерация 09.09.2026](https://yageogroup.com/component-documentation/download/specsheet/RL2512FK-070R1L).
Описание магазина про «тонкоплёночный» тип и «250 В» не используется:
производитель задаёт thick film и максимальное непрерывное падение 0,3 В.

J702 показывает **два конца последовательного участка стенда**, а не разъём
LW. Положительный контролируемый ток идёт от pin 1 (SHUNT_UPSTREAM_P)
к pin 2 (SHUNT_DOWNSTREAM_P). IN+ и IN− подключены с соответствующих сторон.
Тяговый ток через этот шунт не предполагается.

[CHARGE-SENSE-01 v0.1](../../docs/charge-sense-paths.md) теперь содержит
DC-контрпример: шунт между BAT и плюсом сборки показывает около 302 мА,
когда нижняя ячейка получает 400 мА при верхней балансировке. Один порог
348 мА не покрывает обе ячейки. Два канала с общим запретом — следующее
предложение для оценки; данный лист по-прежнему содержит только один.

В какой именно участок BQ25887 включить R702, ещё нужно согласовать по общей
схеме. Нельзя считать его автоматически соединённым с BAT или менять SNS,
MID/CBSET ради компенсации падения. Один такой шунт не доказывает контроль
всех токов ячеек/балансировки и не заменяет защиту батареи. Обрыв измерения,
обратный ток и обход через землю также остаются открытыми проверками.

Номинальный расчёт даёт 348 мА. При 25 °C частичная оценка — 331…365 мА;
добавление только TCR шунта при предполагаемой температуре его тела 125 °C
расширяет её до 313…388 мА. Это не рабочая температура, назначенная машинке,
и не гарантированный диапазон всего узла: TCR R701, самонагрев, пульсации и
разводка не учтены. Номинал 1 Вт при 70 °C не доказывает допустимость
постоянного или импульсного режима на нашей плате.

## Проверки и ограничения

ERC=0, 7 компонентов, 23 вывода включая EP и незадействованный HYS.
Числовая распиновка проверяется отдельно от генератора. Шесть изменённых
копий схемы выявляют перепутанное измерение, прозрачный LATCH, выключенный
ENABLE, режим 100 мкс, ошибочный выход и обход шунта. Интерфейс ошибки
сопоставляется со свежим экспортом permit v0.4.
Итоговый PDF просмотрен; подписи не перекрывают компоненты и рамку документа.

Шесть цифровых сценариев используют фиксированные окна и идеальные питания
**после инициализации**. После срабатывания последующее снижение тока и
застывший/переключающийся ARM сохраняют Q=0 и CD в запрете. Модель также
показывает ограничения: повторяющиеся импульсы по 40 мкс с паузой 60 мкс
могут не вызвать ошибку; обратная полярность измерения не выявляет положительное
превышение. Фаза окон, аналоговые задержки, шум, запуск и реальный ток
не моделируются. Если сама ошибка потеряна при просадке/сбросе детектора,
новый ARM опять может разрешить заряд — этот переход остаётся непроверенным.

До допуска LW нужны осциллограммы полного пути от роста тока до его
прекращения, пик/длительность/остаточная энергия и допустимые параметры LW.
Компаратор с настройкой 50 мкс не является мгновенным ограничителем тока.
14 сентября пользователь подтвердил паяльный фен; нагревательной плиты нет. Лабораторного БП с ограничением тока нет, доступны только обычные USB-зарядки; доступа к осциллографу нет. Поэтому измерение коротких импульсов и испытание защиты на предусмотренном стенде пока недоступны.

```powershell
& build/tooling/kicad-10.0.6/bin/python.exe tools/build_charge_overcurrent.py
& build/tooling/kicad-10.0.6/bin/python.exe tools/verify_charge_overcurrent.py
& build/tooling/kicad-10.0.6/bin/python.exe tools/calculate_charge_guard.py
```

INA300 уже включён в смету. [Шунт ChipDip 9030002190](https://www.chipdip.ru/product/1vt-2512-0.1-om-1-rl2512fk-070r1l-chip-rezistor-smd-yageo-9030002190)
на 14 сентября стоит 8 ₽, **минимум 10 шт., кратность 5**. Для 1/4/6 машин
покупка 10 шт. стоит 80 ₽. В карточке 9 шт. в Чебоксарах и 5028 в Москве;
онлайн-заказ минимальной партии ориентировочно доступен в магазине 18 сентября
бесплатно. Продажа меньшего количества на месте не подтверждена. Заказов нет;
R701/C701, монтаж и полная плата ещё не оценены.

Символ INA300 создан по TI, пассивные символы взяты из локальной библиотеки:
[происхождение и лицензия](../charge-core/NOTICE.md).

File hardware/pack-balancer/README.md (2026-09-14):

# Балансировщик на стороне ячеек

14 сентября 2026. **PACK-BAL-01 v0.1: отдельная схема BQ29209 для стенда.**
Это часть исследования резервного зарядника A на BQ25886. Есть 12 позиций,
схема KiCad и PDF; платы, монтажа и измерений нет. Полная BMS, управление
зарядом каждой ячейки и выбор A вместо B этим не завершены.

[PDF](pack-balancer.pdf) · [KiCad](pack-balancer.kicad_pro) ·
[Схема](pack-balancer.kicad_sch) · [BOM](bom.csv) ·
[Проверка](../../docs/evidence/pack-balancer-verification.json)

## Что даёт вариант A

У [BQ25886](../charge-core/README.md) зарядный ток задаётся резистором:
сброса регистра к 1,5 А, как у BQ25887, здесь нет. Но BQ25886 регулирует
напряжение всей сборки. BQ29209 добавляет небольшую балансировку и
**вторичное** обнаружение перенапряжения около 4,30 В на ячейку.
Он не превращает эту пару в регулятор 4,20 В каждой ячейки.

Поэтому нельзя удалить все защитные цепи и объявить A готовым/более дешёвым.
Для A остаются нормальное ограничение напряжения каждой ячейки,
силовой запрет, защита при разряде, политика USB и полное сопряжение.
Для B остаётся независимая защита программно задаваемого тока с учётом
[обходной ветви балансировки](../../docs/charge-sense-paths.md).

## Электрические границы

Все сигналы этого листа относятся к **BAT_RAW_N**, настоящему минусу
ячеек до низкобокового отключающего ключа защиты. Здесь нет USB_GND,
AUX_3V3, CHG_GND или FAULT_BUS_N. Это осознанно отдельная область схемы,
а не утверждение о гальванической изоляции уже готовой платы.

| Интерфейс | Назначение |
| --- | --- |
| J801.1 BAT_RAW_P | Плюс двух ячеек до возможного разрыва защиты |
| J801.2 BAT_MID | Средняя точка двух ячеек |
| J801.3 и .4 BAT_RAW_N | Оба контакта — настоящий минус ячеек; дублирование только для логического стендового интерфейса |
| J802.1 BAL_EN_N | Низкий уровень относительно BAT_RAW_N разрешает балансировку; R805 100 кОм подтягивает к BAL_VDD для запрета |
| J802.2 BAL_OVP_RAW | Активный высокий выход вторичного OVP; не открытый сток и не совместимый напрямую с MCU сигнал |
| J802.3 BAL_VDD | Отфильтрованное питание от батареи, не выход 3,3 В и не питание внешней нагрузки |
| J802.4 BAT_RAW_N | Батарейная опора измерения; не соединять автоматически с землёй USB/отладчика |

J801 — обозначение узлов имитатора, **не установленный порядок контактов LW**.
J802 пока не подключён к существующим MCU/permit. Нужны согласование
уровней и передача разрешения/ошибки без обхода отключающего ключа BMS.
Просто соединить земли ради удобства сигнала нельзя.

Почему это необходимо: пусть две ячейки имеют по 3,7 В относительно
сырого минуса, а низкобоковая защита отключена. Нагрузка может подтянуть
защищённый минус к плюсу 7,4 В. Тогда средняя точка 3,7 В относительно
ошибочно выбранной земли оказывается **−3,7 В**. TI прямо описывает эту
проблему и рекомендует оставлять BQ2920x подключённым на стороне ячеек:
[ответ TI про low-side cutoff](https://e2e.ti.com/support/power-management-group/power-management/f/power-management-forum/631424/bq29200-bq29200-use-with-an-under-voltage-cutoff-ic).
Числа здесь — наш DC-контрпример, не измеренная осциллограмма.

## Обвязка и ограничения

Основание: [TI SLUSA52C, март 2016](https://www.ti.com/lit/gpn/bq29209),
таблица выводов, §§7.3–7.6, 8.3 и рисунок 9. Прочитана и визуально сверена
[копия производителя у ChipDip](https://static.chipdip.ru/lib/799/DOC059799688.pdf),
25 страниц, SHA-256 `5d78b2ee2f7e9e8a1e3e1a45afaf8842c88b30fa5ff7b72a738fd8188a1fce7f`.

- U801: именно BQ29209DRBR; EP получает локальный номер 9 и BAT_RAW_N.
  BQ29200 имеет другой порог и не является заменой по одному названию семейства.
- R801/R802/R803 = 100 Ом, питание и два измерительных фильтра.
  **C802 включён между BAL_VC2 и BAL_VC1**; C803 — между BAL_VC1 и BAT_RAW_N.
  Верхний конденсатор нельзя автоматически переносить на землю.
- R804 = 120 Ом. Таблица 7.6 даёт для такого RCB ориентир 5/10/15 мА
  min/nom/max при указанных там условиях. Это не обход 250 мА и не
  подтверждение времени выравнивания наших батарей.
- C804 = 100 нФ: номинальная задержка OVP 0,9 с. С коэффициентом
  5,5…13,5 с/мкФ и **предполагаемой эффективной** ёмкостью ±10% получается
  0,495…1,485 с. Выбранного конденсатора с учтёнными температурой/смещением
  пока нет. Это задержка детектора, а не время физического разрыва тока.
- OUT в специфицированном режиме без нагрузки может достигать 9,5 В.
  Прямое подключение к FAULT_BUS_N или 3,3-В GPIO недопустимо.
- Балансировку нужно запрещать при низком напряжении; TI рекомендует
  отключение при VDD ниже 6 В. Одна подтяжка R805 задаёт исходный запрет,
  но политику включения и переходы питания не реализует.

В обозначениях RCB1/RCB2 у TI есть неоднозначность: формулы и схема
используют похожие имена внешних резисторов и внутренних сопротивлений,
а численные значения последних отсутствуют в таблице. В [разборе TI](https://e2e.ti.com/support/power-management-group/power-management/f/power-management-forum/667742/bq29200-bq29200-cell-balancing)
это отдельно отмечено. Не выводим точный балансировочный ток из внешних
100 Ом или не гарантированных оценок внутренних ключей; проверять оба
направления на имитаторе. Входные резисторы 100 Ом выбраны из рекомендуемого
диапазона 100…1000 Ом, а не как копия 160/260 Ом рисунка 9.

Небольшой балансировочный ток не гарантирует удержание верхней ячейки
при большом разбалансе во время заряда. Работа только до срабатывания
вторичного порога 4,30 В не принимается за нормальный зарядный алгоритм.
Также остаются расход от батареи при хранении, обрыв средней точки,
порядок подключения и необходимость отключать балансировку при разряде.

## Проверка и воспроизведение

```powershell
& build/tooling/kicad-10.0.6/bin/python.exe tools/build_pack_balancer.py
& build/tooling/kicad-10.0.6/bin/python.exe tools/verify_pack_balancer.py
```

KiCad 10.0.6: ERC без замечаний; сверены 35 соединений, включая EP,
и 12 позиций BOM. Проверка обнаружила пять ошибок во внесённых копиях:
перестановку измерения ячеек, землю после защиты, перенос C802 на землю,
подтяжку разрешения вниз и прямой OVP на шину permit. PDF осмотрен.
Это проверка связей и границ интерфейса, **не работа защиты/балансировки**.
Перед фиксацией хешей генерации нормализуются по `.gitattributes`.

Символ U801 создан по первичной таблице, пассивы заимствованы из локальной
библиотеки с [указанным происхождением](../charge-core/NOTICE.md).
Посадочные места и плата не созданы. BQ29209 уже присутствовал в смете A;
повторно его цену не добавляем. Новых цен, покупок или физического заряда нет.

Следующий этап — нормальный контроль напряжения ячеек для A и согласование
батарейной/USB-областей с первичной защитой. После этого сравнивать полный
размер и стоимость A/B; текущий лист не выбирает победителя.

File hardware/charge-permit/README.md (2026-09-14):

# Аппаратное удержание запрета заряда

14 сентября 2026. **CHARGE-PERMIT-01 v0.4 — кандидат, схема без PCB и монтажа.**
Защёлка теперь соединена с сигнальной цепью CD на двух TMUX1219. Supervisor
питается отдельно от AUX. [Назначение ключей, источник питания, границы
проверки и цены](../../docs/charge-cd-actuator.md). Входное питание и переходные
режимы ещё не согласованы; аккумулятор к этому узлу не подключается.

[KiCad](charge-permit.kicad_pro) · [Схема PDF](charge-permit.pdf) ·
[BOM](bom.csv) · [Отчёт проверок](../../docs/evidence/charge-permit-verification.json)

В v0.4 R402 изменён с 10 на 47 кОм для нагрузки выхода инвертора нового
[интерфейса MCU](../charger-mcu/README.md) не более 100 мкА: резистор и вход
Шмитта дают условно до 82,4 мкА. При предполагаемой суммарной утечке 15 мкА
плавающий ARM ≤0,713 В; это отдельная DC-оценка при исправных питаниях,
не гарантия поведения во время просадки. Остальная схема v0.3 сохранена.

Для J402 подготовлен отдельный [лист watchdog CHARGE-WD-01 v0.1](../charge-watchdog/README.md):
WDO/ENOUT объединены на FAULT_BUS_N, подтяжка остаётся только R401 этого листа.
Сопоставление экспортированных интерфейсов и цифровая модель проверены;
общая PCB, уровни и переходные процессы ещё не проверены.

Для той же J402 подготовлен [INA300 CHARGE-OC-01 v0.2](../charge-overcurrent/README.md)
с постоянно включённым LATCH. Его удержанная ошибка в модели блокирует и новые
фронты ARM. Это не проверка потери питания детектора или фактического тока.

## Состав и основания

- U401 **SN74LVC1G74DCTR**, SM8: D-триггер, D и активный LOW PRE на AUX.
  Активный LOW CLR сбрасывает Q независимо от CLK; Q — **pin 5**, инверсный
  pin 3 не используется. Нужен новый положительный фронт CLK, чтобы получить
  разрешение после сброса. При 3,3 ±0,3 В ограничение скорости входного
  перехода 10 нс/В, поэтому перед CLK/CLR стоят буферы Шмитта.
  [TI SCES794G, сентябрь 2021, §§5, 6.3, 6.5–6.6, 8.4](https://www.ti.com/lit/gpn/sn74lvc1g74).
- U402 **SN74LVC2G17DCKR**, SC70-6: два неинвертирующих буфера Шмитта.
  FAULT_BUS_N: вход 1 → выход 6 → CLR; ARM: вход 3 → выход 4 → CLK.
  Питание pin 5, земля pin 2. Буфер формирует переход для цифрового входа,
  но сам по себе не гарантирует отсутствие помех или достаточную длительность
  импульса ошибки. [TI SCES381N, январь 2015, §§6–7, 9](https://www.ti.com/lit/gpn/sn74lvc2g17).
- U403 **TPS3808G33DBVR**, SOT-23-6: SENSE/pin 5 на AUX, VDD/pin 6 на **CHG_BIAS_3V3**;
  RESET/pin 1 — открытый сток на общей шине ошибок. MR/pin 3 на CHG_BIAS_3V3,
  GND/pin 2 на землю. CT/pin 4 намеренно свободен: задержка отпускания
  12…28 мс, типовая 20 мс при условиях таблицы. Номинальный падающий порог
  3,07 В; допуск ±1,5% при полном температурном диапазоне даёт
  3,02395…3,11605 В. Гистерезис фиксированных версий — до 2,5%; старт
  при любой точке диапазона AUX 3,0…3,6 В не обещается. DBV и DRV имеют
  **разную распиновку**. [TI SBVS050N, август 2026, §§4–6](https://www.ti.com/lit/ds/symlink/tps3808.pdf).

U404/U405 — TMUX1219DBVR, селекторы активного запрета CD. Питаются
от CHG_BIAS_3V3; LOW ошибки выбирает запрет независимо от Q. Их распиновка
и расчёт приведены в [CHARGE-CD-01](../../docs/charge-cd-actuator.md).

Добавлен [U406 TPS70933DBVR с обвязкой](../../docs/charge-bias.md): отдельное
питание 3,3 В для supervisor и TMUX. EN намеренно свободен, не на IN.

Всего 23 позиции: шесть IC, семь конденсаторов, шесть резисторов и четыре
логических интерфейса. Разъёмы показывают границы узла; необходимость
физических соединителей и посадочные места определяются на общей плате.
Символы IC нарисованы в проекте по таблицам выводов. R/C/соединители/PWR_FLAG
скопированы без изменения из [локальной библиотеки KiCad](../charge-core/NOTICE.md),
CC-BY-SA 4.0 с исключением KiCad; [текст лицензии](../usb-port/RaceRemote_USB.pretty/LICENSE.md).

## Интерфейс и порядок разрешения

| Интерфейс | Контракт предложения |
| --- | --- |
| J401.1 / .2 | AUX_3V3 / USB_GND от TPS709. Ни raw USB, ни батарея, ни второй источник питания |
| J401.3 / .4 | CHG_SUPPLY_INPUT / USB_GND: защищённый вход зарядника к U406. CHG_BIAS_3V3 теперь локальный выход регулятора, 3,0…3,6 В; не объединять с AUX |
| J402.1 / .2 | Общая FAULT_BUS_N / земля. Внешние watchdog и токовая защита только замыкают на землю или отпускают |
| J403.1 | ARM от инвертора MCU, по умолчанию LOW через 47 кОм. HIGH — уровень AUX; точные запасы и переходы проверить при интеграции |
| J403.2 | FAULT_BUS_N: MCU может читать и отзывать разрешение открытым стоком. Никогда не выдавать push-pull HIGH |
| J403.3 / .4 | Наблюдение PERMIT_Q / земля. Вход MCU не должен питать обесточенный узел |
| J404.1 / .2 | **CHARGER_CD / земля** к BQ25887 pin 3. HIGH запрещает, LOW позволяет при выполнении остальных условий зарядника. Только сигнальный ток |

**v0.2 → v0.3:** J401.3 теперь вход U406, старый CHG_BIAS заменён
локальным CHG_BIAS_3V3. [Границы питания и переходов](../../docs/charge-bias.md).

**Ранее v0.1 → v0.2 несовместимы:** J401 стал четырёхконтактным; J404 выдаёт
активный HIGH запрет CD вместо активного HIGH разрешения Q. U403 и C403
были перенесены на отдельный CHG_BIAS (в v0.3 — CHG_BIAS_3V3), SENSE
остаётся на AUX. Старые жгуты не применять.

Предложенная последовательность программы: ARM LOW → удерживать запрет
при инициализации и проверках → отпустить собственный открытый сток →
дождаться FAULT_BUS_N HIGH → выдержать минимум 1 мс без новой ошибки →
ARM HIGH минимум 10 мкс → ARM LOW. Это проектные интервалы, не прошивка
и не гарантия тайминга железа. Источники ошибок должны работать независимо
от программы. Watchdog и MCU имеют отдельные листы с сопоставленными
интерфейсами, INA300 и общий запуск/сброс ещё не реализованы. Карта MCU v0.2
использует открытый сток ARM_N через инвертор и назначает revoke/readback.

После корректного сброса LOW на FAULT_BUS_N запрещает Q. Отпускание шины
при ARM, застывшем HIGH либо LOW, сохраняет Q=0. Но повторяющиеся фронты
ARM после отпускания всех ошибок снова устанавливают Q. Это **не защита
от произвольной ошибочной программы**: токовая ошибка должна удерживаться,
а её очистка и повторная проверка должны быть согласованы с отдельным
аппаратным запретом. Обрыв провода открытого стока не обнаруживается этой
схемой. Совпадение фронтов у границы снятия CLR требует анализа времён,
а не ссылки на идеальную таблицу состояний.

## Электрические границы

Подтяжка шины ошибок 10 кОм ±1% даёт до 0,364 мА при AUX=3,6 В;
участники должны выдержать общий ток всех согласованных подтяжек. Не
дублировать её из отдельных схем. R403=47 кОм тянет PERMIT_Q к земле.
При дополнительной внешней нагрузке ≤20 мкА общий HIGH-ток <100 мкА;
это предложение бюджета; вход TMUX и дополнительные нагрузки нужно согласовать.
Шина ошибок и ARM добавляют ток при LOW/HIGH соответственно; полный
бюджет AUX, включая переходные режимы, всё ещё открыт.

Ioff триггера при VCC=0 даёт расчётную границу 0,4747 В на 47 кОм
при условиях соответствующей таблицы. Это **не доказательство LOW при
просадке**. У TPS3808 условие reset от 0,8 В относится к нагрузке 15 мкА;
наша подтяжка 10 кОм не позволяет переносить его на готовый узел.
Питание логики ниже рабочего диапазона оставляет выходы неопределёнными.
Кроме того, конечная задержка supervisor означает, что быстрый спад AUX
может пересечь допустимый минимум до прохождения запрета. Исполнительная
цепь имеет отдельный вход ошибки, но переходный процесс ещё не проверен.
R405=1 МОм добавляет нагрузку шины; условный HIGH ≥2,8697 В приведён
в [расчёте CD](../../docs/charge-cd-actuator.md).

## Проверки и следующий шаг

KiCad 10.0.6 ERC: **0 замечаний**, сверены 37 выводов IC / 75 выводов всей
схемы и значения 23 компонентов. Десять изменённых схем экспортированы
заново: обход CLR, D на земле, SENSE на земле, CLK вместо CD,
питание supervisor от AUX, неверный источник запрета U405 и его SEL от Q,
питание U406 от AUX, обход регулятора питанием TMUX и C407 на входе.
Все ошибки обнаружены. PDF осмотрен, наложений обозначений нет.
Дополнительно проверены 18 комбинаций установившейся логики CD, включая
неизвестный Q и недопустимое питание. Это не проверка переходных процессов.

11 последовательностей идеальной логики используют экспортированные
соединения: старт из неизвестного/обоих состояний Q, три источника сброса,
зависшие уровни ARM, одновременные ошибки и ограничение повторных фронтов.
Без стартового reset модель сохраняет **неизвестное состояние**, а не
подставляет удобный ноль. Это проверка логики соединений, не SPICE,
осциллограмма или доказательство зарядной безопасности.

```powershell
& build/tooling/kicad-10.0.6/bin/python.exe tools/build_charge_permit.py
& build/tooling/kicad-10.0.6/bin/python.exe tools/verify_charge_permit.py
```

Следующая работа — проверка регулятора при малом запасе напряжения и
проверка переходов питания, затем watchdog, удержание/очистка INA300 и
карта MCU. Нужны измерения на имитаторе батареи: отключение после ошибки,
пик и длительность тока, медленный/быстрый спад и восстановление питания.
Готовой зарядки и разрешения подключать LW пока нет.

## Стоимость кандидатов

Карточки прочитаны 14 сентября: все от 1 шт., московский склад, срок
4 дня; в магазин Чебоксар ориентировочно 18 сентября бесплатно. Местного
остатка нет. Потребность/покупка на 1/4/6 машин — 1/4/6 каждого IC.

| Деталь | Цена | Остаток | Расход 1 / 4 / 6 |
| --- | ---: | ---: | ---: |
| [SN74LVC1G74DCTR](https://www.chipdip.ru/product/sn74lvc1g74dctr-trigger-1-elementnyy-texas-instruments-9001599903) | 69 ₽ | 1222 | 69 / 276 / 414 ₽ |
| [TPS3808G33DBVR](https://www.chipdip.ru/product/tps3808g33dbvr-supervizor-3.07v-s-texas-instruments-9000406641) | 32 ₽ | 298 | 32 / 128 / 192 ₽ |
| [SN74LVC2G17DCKR](https://www.chipdip.ru/product/sn74lvc2g17dckr-sdvoennyy-bufer-s-texas-instruments-9000215534) | 45 ₽ | 39 | 45 / 180 / 270 ₽ |

Первые три IC: **146 / 584 / 876 ₽**. С двумя TMUX1219 —
**346 / 1134 / 1536 ₽**; с U406 — **386 / 1294 / 1776 ₽**
([питание CD](../../docs/charge-bias.md)); [предложения ключей](../../docs/charge-cd-actuator.md#стоимость-двух-ключей).
Обвязка, согласование CHG_BIAS_3V3, PCB и монтаж не оценены. Заказов нет.

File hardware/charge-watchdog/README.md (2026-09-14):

# Watchdog зарядного контроллера

14 сентября 2026. **CHARGE-WD-01 v0.1 — предложение: схема и цифровая модель,
без платы, монтажа и проверенного зарядного цикла.**

[Схема PDF](charge-watchdog.pdf) · [KiCad](charge-watchdog.kicad_pro) ·
[BOM](bom.csv) · [Проверки](../../docs/evidence/charge-watchdog-verification.json)

## Назначение и интерфейсы

U501 TPS3431SDRBR следит за импульсами от отдельного зарядного MCU. Его выходы
подключаются к [защёлке разрешения](../charge-permit/README.md), чтобы прекращение
импульсов сбрасывало разрешение. Это отдельный лист проекта, а не уже собранная
общая плата. Watchdog управления движением в ESP32 выполняет другую задачу.

| Интерфейс | Контакт 1 | Контакт 2 | Условие |
| --- | --- | --- | --- |
| J501 | AUX_3V3 | USB_GND | Те же 3,0…3,6 В, что у MCU; не CHG_BIAS, батарея или XIAO |
| J502 | WD_HEARTBEAT | USB_GND | PD6/pin 3 CH32 теперь через инвертор U602; электрические уровни ещё не квалифицированы |
| J503 → permit J402 | FAULT_BUS_N | USB_GND | Открытые стоки WDO и ENOUT; единственная подтяжка R401 на листе permit |

EN и SET1 соединены с AUX аппаратно: MCU не получает линии отключения watchdog.
R501=10 кОм ±1% выбирает заводской таймер; CWD не имеет конденсатора.
R502=47 кОм ±1% задаёт LOW при отключённом MCU; C501=100 нФ — развязка питания.
Тепловая площадка обозначена локальным номером 9; это не девятый вывод корпуса.
Посадочные места и физические разъёмы пока не выбраны.

## Основание выбора

[TI SNVSB66A, октябрь 2021](https://www.ti.com/lit/gpn/tps3431), таблица 5-1,
§§6.5–6.6, 7.3–7.4: WDI реагирует на спад; выбранные тайм-аут и импульс ошибки
составляют 170/200/230 мс (min/typ/max). При активной ошибке WDI игнорируется.
WDO и ENOUT допускают объединение. Пороги WDI: LOW ≤0,3×VDD, HIGH ≥0,8×VDD;
минимальная длительность импульса 50 нс. IDD до 19 мкА при табличных условиях.
VOL ≤0,4 В задан при VDD=5 В и 3 мА, что само по себе не доказывает уровень
на нашей шине 3,3 В. Ниже POR выходы нельзя считать определёнными.
Для старта указаны минимум 300 мкс после достижения 1,8 В и типичная оценка
CWD 381 мкс; это не измеренный срок готовности всего узла.

## Предложение для программы и границы защиты

Предлагается подавать спад не реже одного раза за 50 мс, HIGH не короче 10 мкс,
только после завершённого цикла проверок зарядки. Эти числа — запас проекта,
не результат испытаний и не написанная прошивка. Автономный PWM или прерывание,
продолжающее работать при зависшем основном цикле, не должны кормить watchdog.
Перед ARM нужны успешная инициализация, действительная квалификация источника,
проверки батареи/зарядника и наблюдаемая отпущенная FAULT_BUS_N. Одной задержки
по типичному tINIT недостаточно.

При зависании WDI в HIGH или LOW появляется ошибка. В модели при исправных
питаниях она очищает Q и переводит CD в запрет. После окончания импульса ошибки
Q остаётся нулём, если ARM замер. Однако новые ошибочные фронты ARM могут
повторно разрешить заряд после отпускания всех ошибок. Быстрые импульсы WDI
тоже принимаются: TPS3431 не проверяет смысл работы программы. Для полного
узла ещё нужны независимая токовая защита, корректное удержание ошибок и
политика восстановления. 230 мс не являются пределом полного отключения тока
и не закрывают проблему сброса BQ25887 к 1,5 А.

Расчёт при AUX ≤3,6 В: существующая подтяжка FAULT требует до 0,364 мА,
R502 при HIGH — до 77,4 мкА. Подтяжка CWD может потреблять ток во время оценки;
нельзя считать весь узел потребляющим только IDD микросхемы. Нужны суммарные
утечки WDO/ENOUT и остальных участников шины, запас LOW/HIGH при AUX 3,0…3,6 В,
переходы питания и проверка выходного уровня конкретного GPIO CH32.

## Что проверено и что делать дальше

KiCad 10.0.6: ERC без замечаний, 7 компонентов, 21 соединение включая EP.
Числовая карта выводов сверена независимо от генератора. Проверка обнаружила
пять внесённых в копии схемы ошибок: отключённые EN/SET1, заземлённый CWD,
ошибочный выходной контакт и отделённый ENOUT. Текущий лист permit экспортируется
заново и проверяется перед сопоставлением J503/J402.

90 дискретных последовательностей охватывают сочетания min/typ/max обоих
таймеров, обычные/быстрые/отсутствующие импульсы, зависание HIGH/LOW и оба
замерших состояния ARM. Модель начинает работу **после явной инициализации
при исправных питаниях**. Это проверка логики проекта, не симуляция аналогового
старта, просадки, фронтов, метастабильности или физического отключения батареи.
PDF просмотрен: подписи и интерфейсы читаемы, наложений не обнаружено.

[Интерфейс MCU v0.2](../charger-mcu/README.md) уже назначает ARM/revoke/readback
и heartbeat через инвертор. Его J603 сопоставлен с J502 этого листа.
Следующий шаг — постоянная токовая ошибка INA300, общая политика источника,
схема питания и испытательный стенд. Пока нет общей PCB, программы зарядного
MCU и испытаний заряда LW.
TPS3431 уже учтён в общей части сметы A/B: повторно добавлять стоимость IC не
нужно. Пассивные компоненты/монтаж этого листа не оценены; старые цены и наличие
не обновлялись, заказов нет.

Воспроизведение из корня репозитория:

```powershell
& build/tooling/kicad-10.0.6/bin/python.exe tools/build_charge_watchdog.py
& build/tooling/kicad-10.0.6/bin/python.exe tools/verify_charge_watchdog.py
```

Генератор использует локальные символы R/C/разъёмов из charge-core и собственный
символ TI. Происхождение пассивных символов см. в [charge-core](../charge-core/README.md).
В отчёте сохранены хеши исходников, схемы, PDF и входов проверки permit.

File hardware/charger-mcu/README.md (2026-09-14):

# Интерфейс зарядного MCU

14 сентября 2026. **CHARGE-MCU-01 v0.2 / CHARGE-IO-01 v0.1 — кандидаты.**
Есть схема, распределение выводов и проверки соединений. Программа CH32,
общая PCB, монтаж и физический заряд ещё не выполнены.

[PDF](charger-mcu.pdf) · [KiCad](charger-mcu.kicad_pro) · [BOM](bom.csv) ·
[Карта 20 выводов](../../docs/charger-mcu-pins.csv) ·
[Отчёт](../../docs/evidence/charger-mcu-verification.json) ·
[Выбор MCU и ограничения](../../docs/charger-mcu.md)

## Что изменилось

PD4 вместо необязательного PACK_SENSE читает PERMIT_Q. PA1 вместо LED
подключён к FAULT_BUS_N: открытый сток для запрета и чтение фактического
входа для наблюдения ошибки. STATUS_LED пока исключён из карты, но индикация
готовой машинки остаётся отдельной задачей. SWIO/PD1 и резерв NRST/PD7 сохранены.

Для ARM, heartbeat и запроса источника добавлен **U602 SN74LVC3G14DCTR**.
Это три инвертора Шмитта с подтяжками входов 10 кОм к AUX. MCU использует
открытый сток: отпущенный вывод → HIGH на входе U602 → LOW на выходе.
Замыкание вывода на землю создаёт HIGH на соответствующем выходе.
Это меняет полярность относительно карты v0.1; старую программу/проводку
нельзя переносить механически. Исполняемой программы ещё нет.

По [WCH CH32V003, таблица 3-17](https://www.wch-ic.com/downloads/CH32V003DS0_PDF.html)
для CMOS-выхода приведён HIGH 2,3 В при табличной нагрузке. Этого недостаточно,
чтобы доказать прямое согласование с WDI ≥0,8×AUX и прежним запросом источника
≥2,8 В. Схема с открытым стоком получает HIGH через резистор от AUX; она не
опирается на предположение о гарантированном HIGH GPIO, равном питанию.

[TI SCES367J, ноябрь 2013](https://www.ti.com/lit/gpn/sn74lvc3g14):
выводы DCT 1→7, 3→5, 6→2 инвертируют; VCC=8, GND=4. При нагрузке ≤100 мкА
в таблице заданы VOH≥VCC−0,1 В и VOL≤0,1 В. Входы Шмитта допускают медленные
переходы. Пороги приведены для отдельных точек VCC; при 3 В VT+≤2,2 В,
VT−≥0,6 В. Это не интерполированная гарантия порогов во всём диапазоне AUX.

Чтобы нагрузка ARM укладывалась в этот режим, **R402 на листе permit v0.4
изменён с 10 на 47 кОм**. Старый permit v0.3 не соответствует новой расчётной
нагрузке. Остальные функции permit, CD и отдельного питания сохранены.

## Сигналы и исходные состояния

| Контакт MCU | Режим и действие | Внешний результат |
| --- | --- | --- |
| PD5/pin 2 ARM_N | Открытый сток; LOW, затем отпускание | Импульс HIGH ARM; положительный фронт разрешает защёлку при отсутствии ошибок |
| PD6/pin 3 WD_HEARTBEAT_N | Открытый сток; LOW, затем отпускание | HIGH WDI, затем спад; только после успешного цикла проверок |
| PD0/pin 8 SOURCE_REQUEST_N | Открытый сток; LOW запрашивает источник | SOURCE_REQUEST HIGH; это ещё не аппаратно квалифицированный SOURCE_ALLOW |
| PA1/pin 5 FAULT_BUS_N | LOW запрещает; отпустить и читать вход | Общая шина ошибок; нельзя выдавать push-pull HIGH или читать только выходной регистр |
| PD4/pin 1 PERMIT_Q | Цифровой вход | Наблюдение Q; не команда и не прямое измерение CD/тока |

При исправном AUX и отпущенных GPIO все три выхода U602 установятся в LOW.
**Отпускание ARM_N не очищает уже установленное Q.** Для обычной остановки
заряда программа должна также притянуть FAULT_BUS_N к земле; watchdog остаётся
независимым средством обнаружения отсутствующих импульсов. Замершие LOW на
выводах MCU удерживают соответствующие выходы HIGH; последствия зависания
проверяются совместно с watchdog и аппаратными ошибками.

До включения режима открытого стока выходной регистр должен быть подготовлен
к отпусканию, внутренние подтяжки выключены. Конкретные регистры, reset/option
bytes, блокировка конфигурации GPIO и порядок инициализации ещё не реализованы.
Указанное исходное состояние — условие схемы, не измерение загрузки CH32.
MCU не получает контактов отключения/очистки INA300; способ восстановления
после токовой ошибки пока открыт и не считается реализованным.

## Соединения с другими листами

J602 совпадает с permit J403; J603 — с watchdog J502; J605 — с USB-detector J303.
Для этих трёх интерфейсов проверяются свежие экспорты схем. I²C/INT/BC_EN и
FAULT не получают вторых подтяжек. Отдельная общая PCB ещё не создана.

J604 передаёт запрос в будущую аппаратную политику источника: его нельзя
просто соединить с SOURCE_ALLOW входного ключа. CC и поведение при смене
источника/просадке/зависании остаются частью незавершённого проекта.
J607 — логический SWIO/RESET/AUX/GND, не распиновка WCH-LinkE. AUX берётся
только от U202; питание программатора с ним не объединять. NRST option bytes
ещё предстоит настроить. J608 — резерв диагностики: к нему нельзя подавать
напряжения батареи или VBUS без отсутствующих пока делителей/защиты.

Условные расчёты: каждый активный запрос нагружает GPIO примерно до 0,369 мА;
ARM — до 82,4 мкА с входом Шмитта; WDI — до 97,4 мкА при **предположенной**
внешней нагрузке 20 мкА. Для SOURCE_REQUEST выделен бюджет ≤100 мкА, который
нужно соблюсти при разработке следующего каскада. При AUX=3 В и суммарной
утечке входа 6 мкА его отпущенный HIGH ≥2,9394 В. Промежуточные напряжения,
суммарный бюджет AUX, реальная утечка WDI/FAULT и все переходы требуют проверки.

## Проверки и воспроизведение

ERC=0, 17 компонентов, 70 соединений. Числовые карты пакетов и CSV сверены
независимо от генератора; проверка обнаруживает шесть изменённых схем и один
ошибочный режим GPIO. Восемь установившихся комбинаций запросов и последовательность
ARM/revoke проверены в цифровой модели. Это не доказательство физической
работы зарядника или полноценная симуляция питания.
PDF нового листа и обновлённого permit просмотрены; наложений подписей не обнаружено.

```powershell
& build/tooling/kicad-10.0.6/bin/python.exe tools/build_charger_mcu.py
& build/tooling/kicad-10.0.6/bin/python.exe tools/verify_charger_mcu.py
```

U601 уже учтён в смете. Дополнительный U602 найден в ChipDip за 57 ₽ от одной
штуки: [8062697920](https://www.chipdip.ru/product/sn74lvc3g14dctr-texas-instruments-8062697920),
71 шт. в Москве, 4–7 дней, ориентир магазина Чебоксар 20 сентября бесплатно.
Снимок 14 сентября, не заказ. Расход на 1/4/6 IC: 57/228/342 ₽.
Вариант [8025336861](https://www.chipdip.ru/product/sn74lvc3g14dctr-texas-instruments-8025336861)
по 51 ₽ требует минимум 11 шт. за 561 ₽ и для 1/4/6 дороже. Обвязка,
плата, программатор и монтаж пока не включены в полную стоимость.

Пассивные символы взяты из локальной библиотеки charge-core; её происхождение
описано в [README](../charge-core/README.md). Символы WCH/TI созданы по распиновкам.

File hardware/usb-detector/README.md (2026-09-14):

# Детектор USB-зарядника PI3USB9201

14 сентября 2026. **USB-BC-01 v0.1 — кандидат интерфейса**, не законченная
зарядка и не утверждённая комплектация серии. [Схема PDF](usb-detector.pdf),
[проект KiCad](usb-detector.kicad_pro), [9 позиций BOM](bom.csv),
[соединения](usb-detector.net). Платы и монтажа нет.

PI3USB9201 различает DCP, CDP, SDP и legacy 1/2/2,4 А отдельными статусами.
Это устраняет неоднозначность DCP/Apple у исследованного BQ24392, но требует
управления по I²C. Предлагается отдельный малый MCU, работающий от USB до
включения силового ключа; XIAO и телефон не должны требоваться для зарядки.
MCU, его программа и формирование SOURCE_ALLOW ещё не реализованы.

Источник: [Diodes DS41358 Rev3-2, апрель 2025](https://www.diodes.com/datasheet/download/PI3USB9201.pdf),
стр. 2, 4–6, 8–9. Локально проверен PDF SHA256
`a7e2f9d88e6c7a88cf66db10ac9e9803a6dcf17959ff618c9ed46f2491937b0b`.
Таблицы прочитаны по изображениям страниц, поскольку текстовый слой неполон.

## Соединения

| Интерфейс | Назначение |
| --- | --- |
| J301.1/.2 | AUX_3V3 / USB_GND от TPS70933 до ключа. Предлагаемые 3,0…3,6 В. Второй источник, батарея и прямой VBUS запрещены |
| J302.1/.2 | PORT_DP / PORT_DM с физического USB-C; U301 pins 8/7 соответственно |
| J303.1/.2 | BC_SCL / BC_SDA, I²C с подтяжками 4,7 кОм к AUX; предложено 100 кГц |
| J303.3 | BC_INT_N, открытый сток с подтяжкой 10 кОм; событие, не разрешение зарядки |
| J303.4 | BC_EN_N, активный LOW. Подтяжка 47 кОм к AUX выключает детектор при высокоомном выходе MCU; управление открытым стоком |
| Земля MCU | Общая с J301.2; отдельного контакта земли на J303 нет |

У U301: USB+ pin 1 и USB− pin 2 — сторона USB-трансивера, здесь свободны.
NC pin 6 свободен; GND pin 9 и ADDR pin 10 на USB_GND; VDD pin 12 на AUX.
ADDR=GND задаёт **7-битный адрес 0x5F**; 0xBE/0xBF — адресные байты с R/W,
их нельзя передавать как 7-битный адрес драйверу.
Внешние D+/D− не соединяются с локальными CORE_DP/CORE_DM BQ25886.
Второй активный BC-детектор на PORT_DP/DM не допускается.

C301=100 нФ входит в общий предел эффективной ёмкости AUX ≤47 мкФ.
200 мкА активного тока IC — типовое значение без указанного максимума:
оно не доказывает соблюдение общего бюджета AUX 10 мА. Предельный ток MCU,
подтяжек и детекторов нужно посчитать совместно и измерить.

Статическая оценка при 3,0…3,6 В и допуске резисторов 1%: ENB ≥2,763 В
при утечке 5 мкА; ток подтяжки INT ≤0,364 мА, каждой линии I²C ≤0,774 мА.
Для условных 100 пФ расчёт фронта I²C около 402 нс. Это не измерение ёмкости,
сброса при просадке или времени всей цепи разрешения.

## Предлагаемая последовательность MCU

Эта последовательность пока является контрактом для реализации и стенда.
Разрешение ключа держать выключенным независимо от ENB детектора.

1. При стабильном AUX включить детектор через ENB=LOW. Выдержать предложенную
   1 мс; даташит указывает готовность не позднее 500 мкс после включения.
2. После каждого старта очистить старые события чтением регистров 0x02 и
   0x03. Начальное INTB может быть событием включения, а не распознавания.
3. Записать 0x00=0x08: client mode с разрешёнными прерываниями. Host-режимы
   и USB Path ON в машине-потребителе не использовать.
4. Записать 0x01=0x02: запретить автоматическое замыкание USB-прохода,
   сбросить запрос определения. Запускать только при подтверждённом
   ATTACHED.SNK от CC-узла; затем 0x01=0x0A создаёт фронт бита 3.
   Для применения вне USB-C даташит задаёт запуск по наличию VBUS.
   Наш USB-C порт всё равно требует проверки CC и VBUS; соответствующий
   узел ещё не собран. Прямой raw VBUS не подключать к GPIO MCU.
5. Читать Client Status 0x02 после события; проверить связь, корректность
   режима и принадлежность результата текущему подключению. Все неуспешные
   операции и истечение будущего тайм-аута оставляют ключ выключенным.
6. При отсоединении немедленно отозвать разрешение, забыть результат,
   очистить бит запуска и перевести детектор в Power Down (0x00=0x00).
   При сбросе/ошибке питания сначала аппаратный запрет, затем новая
   инициализация; старый результат нельзя восстанавливать из памяти.

Регистры 0x02/0x03 **очищаются при чтении**. Ноль при повторном чтении не
доказывает отсоединение; кэш должен относиться только к текущему подключению
с живыми CC/VBUS. INTB напрямую к SOURCE_ALLOW не подключается.

| Единственный бит 0x02 | Распознанный класс | Предложение для режима ключа ≥1,5 А |
| --- | --- | --- |
| 0x80 | DCP | Кандидат разрешения после полной квалификации |
| 0x40 | SDP | Не разрешать этот режим |
| 0x20 | CDP | Кандидат разрешения после полной квалификации |
| 0x08 | Legacy 1 А | Не разрешать этот режим |
| 0x04 / 0x02 | Legacy 2 А / 2,4 А | Кандидат разрешения после полной квалификации |
| 0x01 | Другой | Не разрешать |
| 0, 0x10, несколько бит | Нет результата / резерв / неоднозначность | Не разрешать; многобитный статус пока не квалифицирован |

Класс не измеряет реальную мощность блока. Полное разрешение дополнительно
проверяет объявление Type-C, VBUS, актуальность результата и ошибки питания.
При объявлении Type-C 1,5/3 А нужен отдельный путь квалификации, согласованный
с BC-процедурой. Тайм-ауты, динамическое изменение CC, обрыв I²C, зависший MCU,
аппаратный watchdog/brownout и повторное включение ещё открыты.

## Проверки и следующий шаг

```powershell
& build/tooling/kicad-10.0.6/bin/python.exe tools/build_usb_detector.py
& build/tooling/kicad-10.0.6/bin/python.exe tools/verify_usb_detector.py
```

[Отчёт](../../docs/evidence/usb-detector-verification.json): ERC=0, проверены
12 выводов IC, внешние соединения, номиналы и 9 позиций BOM. После экспорта
изменённых схем обнаружены три ошибки: DP на DM, подтяжка ENB на землю,
питание интерфейса от raw VBUS. PDF осмотрен как изображение, наложений нет.
Проверки не запускают протокол и не имитируют электрическое распознавание.

Следующий выбор — управляющий MCU и CC-узел с совместимой ревизией Rd,
после чего полная стоимость/размер/число компонентов зарядных вариантов A/B.
Для MCU теперь подготовлен [кандидат CH32V003F4P6 и карта выводов](../../docs/charger-mcu.md);
в [сравнении 0.2](../../docs/charge-node-comparison.md) посчитана известная часть
стоимости обоих вариантов. Схемы MCU/CC/аппаратного разрешения остаются открытыми.
Появление MCU в варианте с BQ25886 требует заново сравнить его с BQ25887;
прежнее преимущество «без MCU» для всего узла больше не предполагается.
Не заказывать серию на основании этой отдельной схемы. Нужны также ESD,
посадочные места, PCB, монтаж и испытания источников без LiPo до объединения
с зарядным ядром, защитой/балансировкой батареи и блокировкой тяги.

## Предложение поставки

Проверено в карточке 14 сентября:
[ChipDip 8052983438](https://www.chipdip.ru/product/pi3usb9201ztaex-2ghz-2-uqfn2020-12-analog-switches-diodes-8052983438),
380 ₽/шт., минимум 1; от 10 — 280 ₽. Указаны 14 шт., 5–6 недель;
склад/страна не названы. Привоз в магазин Чебоксар ориентировочно 23 октября,
бесплатно; местного остатка нет. На 1/4/6 машин расход 380/1520/2280 ₽
только за IC, без MCU/платы/монтажа. Заказов нет.

Предложение [8062433724](https://www.chipdip.ru/product/pi3usb9201ztaex-2ghz-2-uqfn2020-12-analog-switches-diodes-8062433724)
за 130 ₽ требует минимум 3000 шт., то есть 390 000 ₽. Для прототипа/серии
4–6 машин оно исключено; заводская упаковка 3000 в первой карточке сама
по себе не означает минимальную покупку 3000.

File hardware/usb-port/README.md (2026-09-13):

# Пассивная плата зарядного USB-C, ревизия 0.2

14 сентября 2026. **Схема и разводка выполнены, ERC/DRC и сравнение схемы с PCB прошли, плата не изготовлена.** Это плата разъёма с двумя резисторами, подключаемая к отдельному зарядному узлу. Зарядного контроллера, защиты аккумулятора, ограничения входного тока и согласования PD/QC здесь нет. Батарею 2S к VBUS не подключать.

[Открыть PCB](usb-port.kicad_pcb) · [Проект KiCad](usb-port.kicad_pro) · [CAD-размещение](../../cad/usb-port-study.md) · [Проверка DRC](../../docs/evidence/usb-port-pcb-drc.json)

[Схема KiCad](usb-port.kicad_sch) · [Схема PDF](schematic.pdf) · [ERC](../../docs/evidence/usb-port-erc.json) · [Проверка соединений и намеренных ошибок](../../docs/evidence/usb-port-pcb-verification.json)

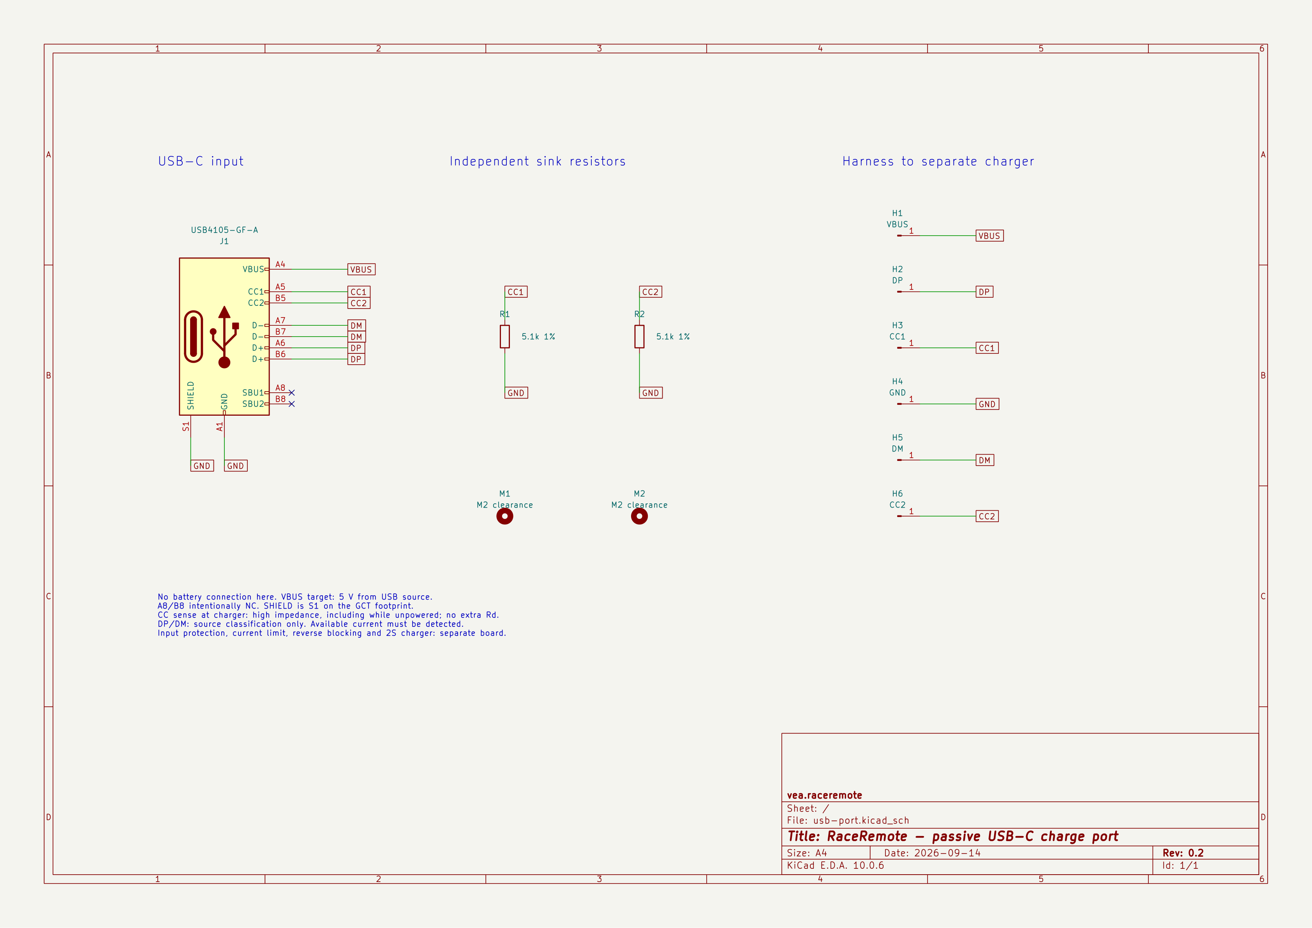
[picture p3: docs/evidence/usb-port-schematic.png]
Электрическая схема платы порта


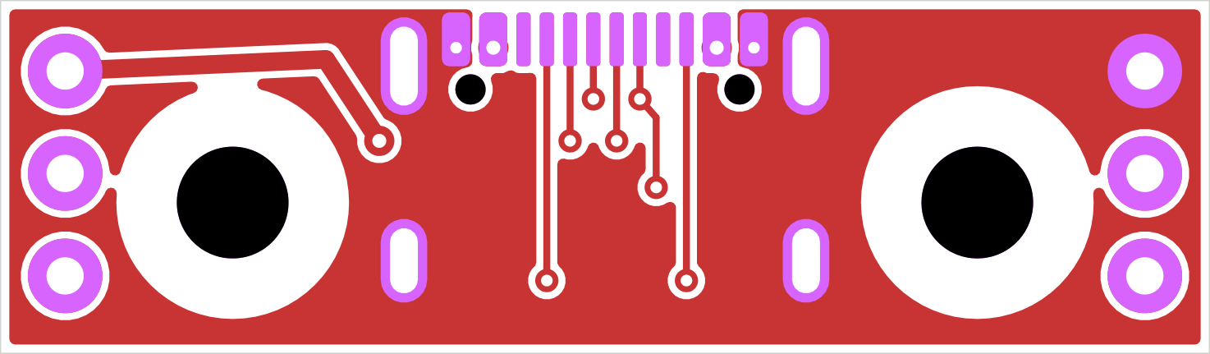
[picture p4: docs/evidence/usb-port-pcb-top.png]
Верх платы, вид сверху


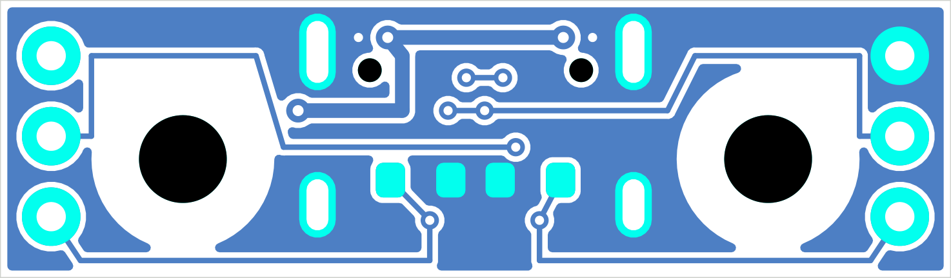
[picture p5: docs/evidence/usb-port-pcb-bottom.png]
Низ платы, также в проекции сверху, без зеркалирования


Плата двухслойная, **26×7,6×1 мм**. Медь 35 мкм предложена для изготовления и использована в CAD; полный стек слоёв с изготовителем ещё не согласован. Разъём GCT USB4105-GF-A сверху, R1/R2 5,1 кОм ±1% типоразмера 0603 снизу. Два отверстия Ø2,4 мм с зонами без меди радиусом 2,5 мм под металлический крепёж. Шесть площадок Ø1,6 с отверстиями Ø0,8 — для пайки жгута; разъём жгута/калибр провода пока не выбраны. Крепление должно разгружать жгут от натяжения, его конструкция ещё открыта.

При сверке с библиотекой обнаружено: в прежнем CAD при X входа 58,5 мм задние площадки USB выходили за плату на 0,33 мм. Сдвиг входа до X=59,1 мм даёт зазор меди до заднего края **0,27 мм**. Ширина платы в CAD увеличена с 22 до 26 мм для пайки жгута за пределами крепёжных зон. Передняя кромка PCB осталась X=58,5 мм: корпус разъёма выступает за неё на 0,6 мм; отдельный вырез под вход не потребовался. [Геометрия площадок и отверстий](geometry.json) экспортируется из KiCad в OpenSCAD.

## USB-PORT-01, предложение v0.2

Участники: зарядный USB-C ↔ плата порта ↔ жгут ↔ отдельный зарядник. Штатный сервисный USB XIAO к этой плате не подключается.

| Контакт | Цепь | Назначение |
| --- | --- | --- |
| H1 | VBUS | Вход от USB-источника; цель системы — 5 В. К защите/ограничителю входа зарядника |
| H2 | DP | A6/B6 разъёма, линия определения источника |
| H3 | CC1 | A5, отдельный R1 5,1 кОм на GND |
| H4 | GND | Общий провод USB и экран разъёма |
| H5 | DM | A7/B7 разъёма, линия определения источника |
| H6 | CC2 | B5, отдельный R2 5,1 кОм на GND |

На рисунках сверху вниз слева H1/H2/H3, справа H4/H5/H6. Низ показан **без зеркалирования** для сопоставления слоёв, а не как вид при перевороте платы. Сверять маркировку цепей в KiCad перед пайкой; маркировка выводов на самой плате пока не добавлена.

CC1 и CC2 не соединяются друг с другом. На основной плате допускаются только подходящие высокоомные входы измерения CC, в том числе при её обесточивании; вторая пара Rd недопустима. Их допустимые напряжения и защита ещё определить. Резисторы позволяют источнику обнаружить потребитель, но **не разрешают произвольный ток**. Определение доступного тока, защита от ESD/замыканий, запрет заряда при ошибках и защита от обратного питания остаются в проектировании зарядного узла. D+/D− разведены для определения источника; USB 2.0 передача данных, импеданс пары и высокоскоростной интерфейс не заявлены.

Обрыв жгута, одного Rd или неправильное распознавание источника должны приводить к запрету заряда либо к подтверждённому допустимому режиму основной платы. Здесь MCU/логики разрешения нет. При отключении VBUS заряд прекращает основной узел; сам порт не разрешает движение.

Основание для двух Rd: [Renesas, модель USB Type-C Source/Sink, рисунки 5–6](https://www.renesas.com/en/support/engineer-school/usb-power-delivery-03). Распиновка J1 — [GCT USB4105 B4](https://gct.co/files/drawings/usb4105.pdf). A8/B8 (SBU) оставлены без подключений.

## Проверка и её пределы

KiCad **10.0.6**: DRC с повторной заливкой зон — 0 нарушений и 0 неподключённых соединений. Заданные минимумы: дорожка/межцепной зазор 0,15 мм, зазор меди до края 0,20 мм, зазор до отверстия 0,15 мм, переход Ø0,50 с отверстием Ø0,25 мм. Зазор до отверстия выбран с учётом заводского посадочного места: там есть около 0,194 мм до направляющего отверстия. Возможности конкретного изготовителя ещё не подтверждены.

В отчётах сохранены стандартные отключённые проверки KiCad; у площадок жгута и крепёжных отверстий нет отдельных courtyard. Их механические зоны проверяются явно в PCB/CAD. Исключения для получения нуля не добавлялись. **ERC: 0 замечаний; сравнение схемы с PCB: 0 расхождений.** Дополнительно сверены 27 логических выводов экспортированного netlist с площадками PCB, включая повторные контакты питания и экрана. В отдельных копиях намеренно перепутан H3 с CC2 и удалён R1: сравнение обнаруживает соответственно `net_conflict` и `missing_footprint`.

Схема задаёт соединения самостоятельно, без чтения цепей PCB. Символ USB взят из KiCad 10.0.6, обозначение экрана адаптировано `SH` → `S1` под GCT; происхождение и изменения — в [NOTICE](SYMBOLS-NOTICE.md). Для A8/B8 созданы явные NC-цепи KiCad, проводников на них нет. R1: контакт 1 → GND, 2 → CC1; R2: 1 → CC2, 2 → GND. UUID связывают символы с посадочными местами. Изменение 0.2 затрагивает электрические метаданные PCB; расположение и размеры площадок/отверстий сохранены, 42 записи CAD проверены по текущей плате.

ERC/DRC не доказывают допустимый ток/нагрев, отсутствие дефектов пайки, стойкость к статике и работоспособность зарядки. Зарядный узел 2S, крепление жгута и физические измерения остаются открытыми.

Приёмка изготовленного образца: прозвонить пары силовых контактов и экран, отсутствие коротких между VBUS/GND/DP/DM/CC; проверить каждый Rd около 5,1 кОм (при отключённом заряднике). Затем проверить 5-В источник с ограничением тока и обе ориентации A–C/C–C, падение напряжения/нагрев при выбранном токе, крепление и жгут. Эти измерения не выполнены.

## Воспроизведение

Используется Python из KiCad, обычный Python не содержит `pcbnew`:

```powershell
& build/tooling/kicad-10.0.6/bin/python.exe tools/build_usb_port_pcb.py
& build/tooling/kicad-10.0.6/bin/python.exe tools/build_usb_port_schematic.py
& build/tooling/kicad-10.0.6/bin/python.exe tools/verify_usb_port.py
& build/tooling/kicad-10.0.6/bin/kicad-cli.exe sch export pdf hardware/usb-port/usb-port.kicad_sch -o hardware/usb-port/schematic.pdf
uv run --with-requirements tools/cad-requirements.txt python tools/build_usb_port_study.py
```

`verify_usb_port.py` запускает штатные ERC/DRC с `--schematic-parity`, проверяет все разделы JSON независимо от кода возврата CLI, сопоставляет netlist/PCB и проверяет две намеренные ошибки в `build/usb-port-pcb/negative-controls/`. На физические устройства скрипт не воздействует. Для просмотра схемы достаточно проектных библиотек; повторно извлекать полные библиотеки KiCad не нужно. Генератор формата схемы основан на [официальном описании KiCad](https://dev-docs.kicad.org/en/file-formats/sexpr-schematic/).

На этом ПК KiCad извлечён в игнорируемую папку `build/tooling/kicad-10.0.6` из [официального подписанного дистрибутива](https://kicad-downloads.s3.cern.ch/windows/stable/kicad-10.0.6-x86_64.exe). Проверена действительная подпись KICAD SERVICES CORPORATION. Системная установка не выполнялась. Извлечены `bin/*`, `lib/*`, `share/kicad/schemas/*`, `share/kicad/template/*`, `share/kicad/scripting/*` и используемый footprint резистора. На другом ПК можно использовать обычную установку KiCad 10.0.6, изменив пути.

Источники посадочных мест и лицензия — [NOTICE](RaceRemote_USB.pretty/NOTICE.md). Полная стоимость PCB/монтажа, производитель и жгут не выбраны. Разъём есть в [таблице предложений](../../docs/charge-parts.md); резисторы пока указаны как тип/номинал без проверенной цены. Заказов нет.

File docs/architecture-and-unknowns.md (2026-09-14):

# Архитектура и known unknowns

Дата: 2026-09-14. Редакция: 0.3. Статус: требования пользователя и предложения для первого прототипа, не утверждённая электрическая схема. Ближайшие физические этапы и недостающие данные собраны в [first-prototype.md](first-prototype.md).

Пользователь считает общую идею USB-C → плата → зарядка аккумулятора подходящей основой. Это поддержка функциональной организации: выбор зарядника, разъёма, распиновки и гарантии совместимости остаются открытыми.

Уже установлено: 4–6 одинаковых машинок, начать с одной; только дома по ровной поверхности; Android и iPhone; Wi-Fi-управление; сменные кузова; FPV-камера опциональна, минимум 30 FPS, желательно 60 FPS; USB-C; разумный гибкий бюджет и покупка деталей в России. Основа питания — **три имеющихся LW 601844HP, 7,4 В, 600 мА·ч, 20C**, с быстрой заменой. При отказе управления остановка обязательна; при отказе только камеры управление сохраняется.

Пользователь предложил кузов на магнитах. Это приоритетный вариант крепления для CAD-проверки, не требование держать кузов на месте во время замены батареи. План механики — в [battery-and-body.md](battery-and-body.md).

## Предлагаемая организация

### Управление и видео

Общая локальная сеть с точкой доступа. Для езды не нужен облачный сервер или интернет. Телефон выбирает машину, получает право управления, показывает её видео и состояние. Точка доступа передаёт трафик; отдельный игровой сервер для первого варианта не предлагается.

```mermaid
flowchart LR
    Phone[Телефон водителя] <-->|Wi-Fi| AP[Общая точка доступа]
    subgraph Car[Одна машинка]
        Control["XIAO ESP32S3 Sense: управление и видео — кандидат"]
        Camera[Опциональная камера OV3660]
        Driver[Силовой драйвер]
        Motor[Мотор]
        Servo[Рулевой сервопривод]
        Control --> Driver --> Motor
        Control --> Servo
        Camera --> Control
    end
    AP <-->|Команды, состояние и видео| Control
```

Текущий компактный кандидат — XIAO ESP32S3 Sense с OV3660 для управления и видео на одной плате. Для него уже есть совместные окружения `xiao-car-qvga` / `xiao-car-vga` в соседнем репозитории. Получение платы и реальные FPV-результаты не подтверждены. Контроллер самостоятельно следит за свежестью команд; работа видеокода не должна быть условием выполнения остановки.

Прежнее разделение на WROOM и отдельную камеру остаётся вариантом сравнения стендов, не целевой комплектацией по умолчанию. WROOM-32U используется как имеющееся экспериментальное оборудование. Единая плата должна пройти те же требования остановки и независимости управления от отказа видео. Выбор сенсора OV3660 не доказывает 30/60 свежих FPS на телефоне; [план FPV](fpv-bench.md) сохраняет отдельное измерение задержки.

Предлагаемая программная организация:

- Прошивка движения: периодический приём актуального газа/руля, калибровка, измерение питания, тайм-аут команд, управление драйвером и серво.
- Видеомодуль: захват, передача и восстановление потока с ограничением очередей устаревших кадров.
- Приложение: выбор машины, сессия одного водителя, управление, видео, состояние батареи/связи, явное отображение потери видео. По FAIL-01 отказ только видео не блокирует управление и не требует нового разрешения при возврате картинки; прежнее предложение обратного отменено.
- Для управления реализован [Control v1](control-v1.md): один владелец, явный ARM, отсутствие очереди устаревших команд, клиентский тайм-аут 200 мс и watchdog 250 мс. Это текущие настройки стенда, не измеренный тормозной путь.

В Android есть настройка/режим заезда и MJPEG, в прошивке — протокол и программный план привода. [Тесты Samsung с программными серверами](driving-ui.md) прошли; [полные радиосценарии ESP32](drive-device-bench.md) не прошли. GPIO привода выключены, физическая камера и движение не проверены. Прежний аудит заготовки не описывает нынешний объём реализации.

### Питание и USB

Питание и отсек проектируются под три существующих LW 601844HP (2S, 600 мА·ч). Модель и количество заданы; измеряются физические размеры, разъёмы, состояние и уточняется паспортный зарядный ток. Каждая подаренная машинка заряжается от обычного USB-блока; имеющийся у пользователя зарядник остаётся оборудованием стенда. Пользователь разрешил отдельный зарядный порт без данных и дополнительные компоненты. Текущее предложение — зарядный порт на шасси, сервисный USB-C XIAO под кузовом.

```mermaid
flowchart LR
    USB[Зарядный USB-C] -->|VBUS_CHARGE| Input[Защита и лимит входного тока]
    Input --> Charger[Зарядный контроллер 2S]
    Charger --> Battery[Батарея: защита и балансировка]
    Battery --> Switch[Выключатель машинки]
    Switch --> DC[DC-DC и развязка сервисного питания]
    DC --> Logic[XIAO: управление и камера]
    Switch --> Drive[Отключаемое питание силового драйвера]
    DC --> ServoPower[Отключаемое питание серво]
    Service[Сервисный USB-C XIAO] -->|VBUS_SERVICE| Logic
    Service <-->|D+ / D−| Logic
```

Функциональные стрелки не задают порядок подключения к BMS, общую землю, номиналы или разводку проводов. Эти детали должны быть на электрической схеме. Напряжение серво и число DC-DC пока открыты. Питание тяги блокируется при подключённом USB; способ блокировки предстоит спроектировать.

Предложение: USB-питание зарядки 5 В без обязательного QC/PD, заряд при выключенной машинке. Это не гарантирует одинаковую скорость зарядки от любого источника. Зарядный узел определяет допустимый входной ток; сервисный USB не питает зарядник. VBUS двух портов не объединять; питание логики от батареи развязывается от сервисного USB. Подключение обоих кабелей входит в будущую проверку.

M85K/MC002/FMC002 — кандидат внешнего разъёма/замены micro-USB, не ограничение для выбора внутреннего зарядника. IP2326 ещё не выбран: требуется проверить настройку, точность напряжения и завершение заряда малой батареи. Линии определения зарядного источника не соединяются с USB-данными XIAO. Подробности и источники — в [usb-c-power.md](usb-c-power.md).

Для текущего кандидата XIAO Sense управление и камера работают на одном ESP32-S3; прошивка идёт через штатный сервисный USB-C. Владельцу подарка не требуется пользоваться данными или разбираться с прошивкой. Сервисный доступ и восстановление загрузчика остаются задачами сборки и обслуживания.

| Режим — предложение | Движение | Логика | Зарядка |
| --- | --- | --- | --- |
| Езда от батареи | Только после подключения водителя и разрешения | Управление; видео при установленной камере | Нет |
| Зарядный USB, машинка выключена | Заблокировано | XIAO выключена; индикация у зарядного узла | С параметрами выбранной батареи и источника |
| Только сервисный USB от компьютера | Заблокировано | Прошивка и диагностика XIAO | Нет заряда 2S |
| Оба USB одновременно | Заблокировано | Прошивка и диагностика XIAO | От отдельного зарядного источника, после проверки развязки |

### Механическая сборка

Одинаковое шасси, кузов на магнитах с направляющими как основной кандидат, продольно регулируемая электроника. Камеру и зарядный порт предлагается оставить на шасси: кузов снимается без их проводов. Для батареи — доступный сверху фиксатор/кассета после снятия кузова; отдельный выдвижной лоток не обязателен. Зарядный разъём должен быть удобен для подключения и скрываться/маскироваться, например крышкой или вставкой кузова. Заднее расположение и стилизация под выхлоп необязательны. Сервисный USB предлагается оставить под кузовом. Крепление порта, пространство для штекера/пальцев и снятие маскировки ещё проверить в CAD и на печати.

### Android и iPhone

Предложенная реализация — KMP + Compose Multiplatform. Общие слои: протокол, сессия водителя, состояние/настройки, экран управления и индикация отказов. За платформенными интерфейсами оставить декодирование/вывод видео, обнаружение устройств, разрешения локальной сети и жизненный цикл приложения. Для сети можно рассмотреть Ktor с платформенными движками; выбор транспорта и видеокодека ещё открыт. KMP не означает автоматической переносимости нынешнего Retrofit/Android-кода.

Android и iOS указаны как stable для KMP и Compose Multiplatform в [документации JetBrains](https://kotlinlang.org/docs/multiplatform/supported-platforms.html). Для iOS-сборки требуется macOS/Xcode; доступ к Mac/CI и реальные телефоны для замера видео ещё нужно определить. [Подготовка окружения](https://kotlinlang.org/docs/multiplatform/quickstart.html). В этом задании меняется план, исходный Android-проект ещё не мигрирован.

Для стенда — доступные модули и документированные соединения. После проверки — одна воспроизводимая разводка/плата соединений и крепления для всей серии, если это оправдано размерами и стоимостью. Собственная плата с интеграцией всех микросхем не является обязательной целью.

## Реестр известных неизвестных

Реестр обновлён после ответов пользователя: закрытые части явно перечислены в строках, оставшиеся вопросы требуют разработки или проверки. P0 — влияет на архитектуру и проверяется раньше; P1 — закрыть до серии. Бюджет без числового потолка не является блокировкой. Приоритеты предложены агентом. Стендовые измерения требуют физических деталей; работа агента — подбор, схема, CAD, ПО и анализ результатов.
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

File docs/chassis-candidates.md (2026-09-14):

# Кандидаты шасси

Проверено: 13 сентября 2026 года. Статус: изучены источники и геометрия STL, конструкция для серии не выбрана.

## AlexY / zcar

Пользователь считает этот проект близким к желаемому результату; хочет Wi-Fi-управление и опциональную камеру.

Источники:

- [Ссылка пользователя: MakerWorld 26911, profileId 2189745](https://makerworld.com/ru/models/26911-fully-printed-1-28-rc-car-chassis-mini-z-compatibl#profileId-2189745).
- [Исходный репозиторий автора — alexyu132/zcar](https://github.com/alexyu132/zcar). MakerWorld напрямую направляет сюда за актуальными деталями.
- Проверенный HEAD `master`: `4b714e63fa30ed2030a8a48ab15f1e4a5fa380c4`. [README этой ревизии](https://github.com/alexyu132/zcar/blob/4b714e63fa30ed2030a8a48ab15f1e4a5fa380c4/README.md).

### Что подтверждено первичными источниками

По описанию автора: масштаб 1:28, база **90 мм (M)**, задний привод, независимая передняя и шарнирная задняя подвеска. Указан проверенный кузов Kyosho MZQ101 AE86. Универсальная совместимость с любым Mini-Z не заявлена.

В BOM используются мотор 130 для 2S, SG90, отдельные коллекторный ESC и радиоприёмник, четыре подшипника 625 и крепёж M3. Автор даёт ориентиры: батарея до примерно **45 × 23 × 16 мм**, приёмник менее примерно **34 × 22 × 13 мм**. Наши компоненты ещё не примерялись.

В GitHub есть STL и исходник `zcar.skp`. README описывает несколько передач с соответствующими креплениями мотора; раздел сборки не завершён. Часть печати выполняется слоями 0,1–0,15 мм; для нагревающихся деталей рассматриваются ABS/PETG. Репозиторий скачан в игнорируемый `build/upstream/zcar`, STL проверены ниже. Исходник SketchUp пока не редактировался; профиль MakerWorld не проверен по геометрии.

MakerWorld удалось прочитать через браузер после ошибки веб-инструмента. Видимый профиль отличается настройками от README; совпадение файлов профиля с GitHub пока не установлено. Брать набор файлов и BOM нужно из одной зафиксированной ревизии, а не смешивать публикации.

### Проверка файлов CAD

Проверена указанная выше ревизия. Воспроизводимый [скрипт](../tools/inspect_zcar.py) сохраняет SHA-256 файлов, габариты и число связных компонентов в [отчёт](evidence/zcar-mesh-audit.json). Проверка выполнена с Trimesh 5.1.0; стандартная загрузка объединяет совпадающие вершины, исправление отверстий при разделении отключено.

| Файл | Результат |
| --- | --- |
| `stl/zcar.stl` | Сборочная модель, габариты 65 × 123,625 × 35,25 мм; сетка не замкнута, 442 связных компонента. Это не 442 физические детали. Не использовать как готовое единое тело для печати или проверки пересечений объёмов |
| `stl/tray1.stl` | 7 из 7 компонентов имеют замкнутую сетку |
| `stl/tray2.stl` | 14 из 14 компонентов имеют замкнутую сетку |

Единицы STL явно не заданы; миллиметры приняты по размерам деталей из описания автора. Габариты основной рамы в `tray1`, компонент 3: **49,5 × 117,375 × 23,25 мм**. Это внешний размер детали, **не размер свободного батарейного отсека**. Замкнутость сеток не доказывает технологичность печати, прочность или посадки.

Ориентир нашей батареи 49 × 18 × 15 мм отличается от рекомендованных автором примерно 45 × 23 × 16 мм. Последующая [компоновка в CAD](../cad/README.md) нашла поперечное размещение и свободный путь бокового извлечения макета без расширения рамы; прямой подъём пересекает центральную полку. Это проверка габаритного параллелепипеда, а не готовый держатель. Примерка полного объёма батареи с проводами и кузовом остаётся открытой частью MOUNT-01/SWAP-01. Физические размеры трёх батарей ещё не измерены; печать адаптации не начиналась.

Повторить проверку из корня RaceRemote (для нового клона):

```powershell
git clone https://github.com/alexyu132/zcar.git build/upstream/zcar
git -C build/upstream/zcar checkout 4b714e63fa30ed2030a8a48ab15f1e4a5fa380c4
uv run --with trimesh==5.1.0 --with numpy==2.4.6 --with networkx==3.6.1 python tools/inspect_zcar.py build/upstream/zcar --output docs/evidence/zcar-mesh-audit.json
```
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

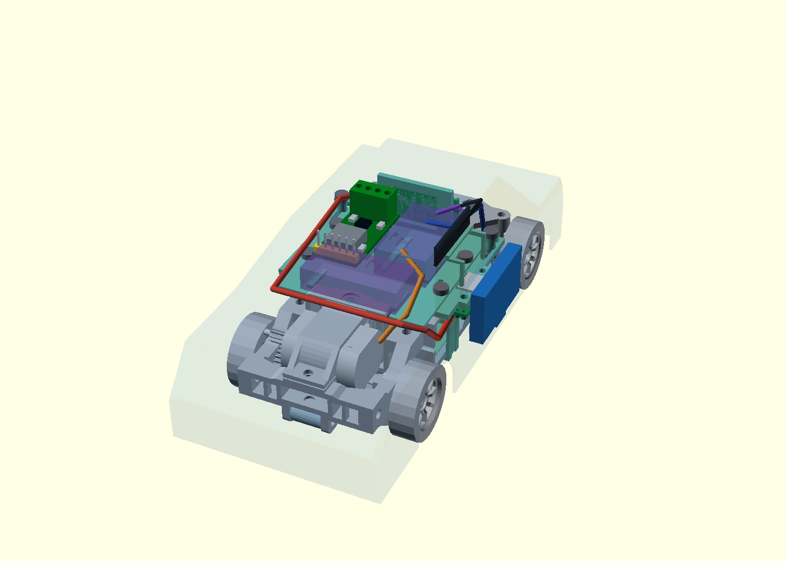
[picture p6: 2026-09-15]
docs/evidence/packaging-v05-overview.png

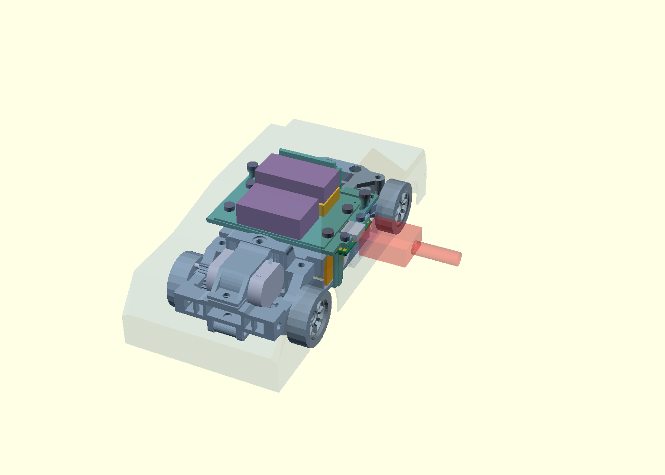
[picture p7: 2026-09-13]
docs/evidence/usb-port-overview.png

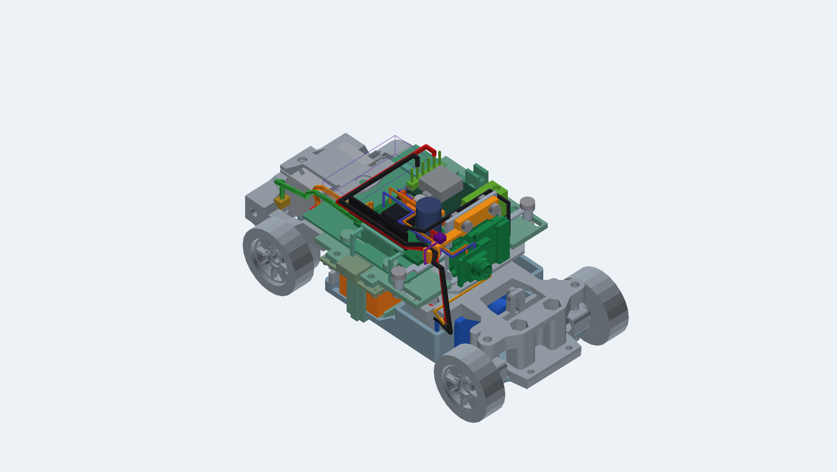
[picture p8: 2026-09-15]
cad/servo-lacing/overview.png

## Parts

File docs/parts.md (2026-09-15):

# Детали и цены

**Текущий вариант внутреннего питания:** [припаянная пара](../cad/direct-logic-harness/README.md). CONN-LOGIC-01 в таблице ниже и CSV теперь только необязательная альтернатива для обслуживания; покупать половину SM ради нового варианта не требуется. Конкретные провод и шнур ещё не выбраны; свежей проверки цен в этом CAD-этапе не было.

**15 сентября — кабельный разъём 5 В:** [Scondar SCT2505FH-02PL100](https://www.chipdip.ru/product/sct2505fh-02pl100-hk0083-0005-rozetka-razem-jst-scondar-9001071847), 86 ₽ за одну половину с проводами, 892 шт. Москва; ориентир самовывоза в Чебоксарах 18 сентября бесплатно. CONN-LOGIC-01 в CSV: 86/344/516 ₽ для 1/4/6 машин **только за эту половину**, без ответной части. Чертёж подтверждает 24 AWG, Ø1,4 мм, 100 ±5 мм — больше прежнего резерва проводки. [Исследование SM](../cad/logic-connector-study/README.md) отделяет примерку габарита JST от неподтверждённой совместимости кабеля Scondar. Полная пара пока не выбрана, не заказана.

**15 сентября — новый кандидат питания логики:** [MAX40200AUK+T, ЧИП и ДИП](https://www.chipdip.ru/product/max40200auk-t-mikroshema-idealnyy-diod-s-sverhnizkim-maxim-9000587524), SOT23-5: 50 ₽ от одной штуки, 97 шт. на складе Москвы; ориентир самовывоза в Чебоксарах — 18 сентября бесплатно. Для 1/4/6 машин только эта микросхема — 50/200/300 ₽. Добавлена в CSV как LOGIC-DIODE-02, **не заказана**. Она заменяет LM66100 в [предложении питания XIAO 0.2](../hardware/xiao-logic-power/README.md); полная стоимость PCB/пассивных деталей неизвестна. Заголовок магазина использует падение WLP, хотя продаётся SOT23; расчёт берёт параметры SOT23 из документа производителя. Совместимость/переходы ещё не подтверждены.

**15 сентября — заказы подтверждены пользователем:** антенна WROOM,
XIAO ESP32S3 Sense с OV3660, F130, SG90 и Waveshare DC5-36-TO-DC3V3-5-M
заказаны и находятся в пути. Пользователь уточнил заказ SG90: STEER-CD-01,
ChipDip 8009579822; STEER-01 из YourDuino остаётся альтернативой, не вторым заказом.
Антенна или XIAO ожидаются ближе к концу сентября. Получение, остальные точные
SKU/количества, оплаченные цены и точные даты ещё не подтверждены. Повторно покупать эти позиции не предлагается;
ценовые таблицы ниже остаются историческими ориентирами, не суммами заказов.

**14 сентября:** добавлена [таблица компонентов встроенной зарядки](charge-parts.md) и отдельный [CSV с минимальными партиями](charge-parts.csv). BQ25887 — 630 ₽ при покупке одной штуки либо 280 ₽ при минимуме 6 штук (1 680 ₽); BQ29209 — 79 ₽ при минимуме 7 (553 ₽). Это микросхемы для проектируемой платы, не готовые зарядные модули. Цены остальных разделов ниже сохраняют прежнюю дату проверки.

Для [CAD-примерки порта](../cad/usb-port-study.md) добавлен GCT USB4105-GF-A: [одна штука 320 ₽](https://www.chipdip.ru/product/usb4105-gf-a-razem-gct-9000729477) или [160 ₽ при минимуме 4 шт.](https://www.chipdip.ru/product/usb4105-gf-a-gct-8020330945). Это гнездо без платы/контроллера; полная стоимость порта ещё не посчитана. Подробности и третий вариант поставки — в таблице зарядных деталей.

В пользовательском Chrome проверен [AliExpress, XIAO S3 Sense Solder, лот 5pcs](https://aliexpress.ru/item/1005008098777836.html?sku_id=12000058133585933): 7 454 ₽ за выбранный лот, бесплатный ПВЗ в Чебоксарах 24–30 сентября. Цена 1pc отдельно ещё неизвестна. Продавец допускает OV2640 **или** OV3660, поэтому нужный сенсор пока не гарантирован; [подробности проверки](aliexpress-shortlist.md#найденный-комплект-s3-с-модулем-камеры). Снимок 13 сентября, заказа нет.

Для самостоятельного поиска пользователя подготовлен [короткий список AliExpress](aliexpress-shortlist.md): точные поисковые названия, количество на прототип, варианты исполнения и цены-ориентиры. Это не проверенные предложения AliExpress. [Примерка конкретных кандидатов в CAD](../cad/candidate-fit.md) отдельно отмечает точные модели и неполные габариты.

**Предпочтения закупки обновлены:** Ozon, Wildberries, AliExpress и «Чип и Дип» (SUPPLY-02). Таблицы ниже сохраняют исследование других магазинов и не являются согласованной корзиной. Новую подборку делать на привычных площадках, проверяя комплектацию, продавца, цену с условиями оплаты и доставку. Для [FPV-стенда](fpv-bench.md) найден резервный XIAO Sense в «Чип и Дип» за 2 960 ₽, но срок 7–8 недель и сенсор OV3660 не подтверждён; готовой корзины стенда пока нет.

Проверка: **2026-09-13**, цены в рублях, доставка не включена. Статус: первоначальная таблица кандидатов, **не утверждённый комплект для покупки**. [CSV для Excel](parts.csv) содержит те же основные позиции и пересчёт количества/стоимости на 1, 4 и 6 машинок.

Конструкция пока ориентируется на [zcar выбранной для изучения ревизии](chassis-candidates.md). Камера опциональна, но её назначение — FPV, минимум 30 FPS на телефоне, желательно 60. Все машинки должны использовать одинаковые выбранные детали. Основа питания теперь задана пользователем: 3 имеющихся LW 601844HP; новые батареи считаются с учётом этого запаса и желаемого числа сменных батарей. Бюджет гибкий, числовой потолок не задан.

## Найденные предложения

Пользователь подтвердил имеющийся зарядник. Новый внешний модельный зарядник в закупку не включать: машинки предназначены в подарок друзьям и должны заряжаться через собственный USB-C от обычного зарядного блока. Встроенный узел 2S остаётся открытой позицией; [исследование компонентов](usb-c-power.md#дополнительный-отбор-для-600-мач-и-снятых-батарей).

### Ближайшие приобретения для испытаний

Это предложение агента на **один стенд**, не полный набор для сборки машинки и не оформленный заказ. Цель — сначала получить измерения связи, камеры и привода, затем выбирать одинаковый комплект для 4–6 машин. Уже имеющиеся батареи, ESP32 и TA6586 повторно покупать не предлагается.

| Деталь | Количество | ₽ | Какую проверку открывает |
| --- | ---: | ---: | --- |
| [Антенна RUICHI P18, BENCH-ANT-01](https://www.chipdip.ru/product/pcb-p18-wifi-2.4g-ipex-1-10cm-vnutrennyaya-ruichi-8030745314) | 1 | 120 | Повторить Wi-Fi-тест существующей WROOM-32U с антенной; стабильность не обещана, остаток 1 шт. |
| [F130-08450 12 V, MOTOR-CD-01](https://www.chipdip.ru/product/f130-08450-12.0v-elektrodvigatel-9000145739) | 1 | 66 | Проверить целевой мотор, не разбирая K989 |
| [SG90 180°, STEER-CD-01](https://www.chipdip.ru/product/servoprivod-tower-pro-sg90-180-s-neylonovym-reduktorom-8009579822) | 1 | 170 | Проверить позиционное управление и механику руля |
| [Waveshare 5 В, POWER-CD-02](https://www.chipdip.ru/product/dc5-36-to-dc3v3-5-m-dc-dc-preobrazovatel-waveshare-9001946092) | 1, выбран пользователем | 670 | Принят для удобства первого стенда после сравнения с 7805; заказ/получение и выбор для серии не подтверждены |

Четыре позиции ChipDip — **1 026 ₽ без доставки**. Минимальное приобретение только для текущего радиостенда — антенна за 120 ₽. Мотор/серво/питание понадобятся позже, когда возобновятся физические работы. Пассивные детали, монтаж, защита батареи, разъёмы и измерительная оснастка в эту сумму не входят; она не является ценой готового привода или машины.

Для FPV отдельно: резерв [Waveshare с OV3660, CAM-WAV-01, Amperkot 43150683](https://amperkot.ru/products/aiot_plata_razrabotki_waveshare_na_baze_esp32s3_s_kameroy_ov3660/43150683.html), 1 шт. за **2 030 ₽**, показаны 2 шт. в Москве. Магазин вне предпочтительных площадок, комплектация/SKU и противоречие 8/16 МБ Flash требуют уточнения. Подтверждён способ доставки СДЭК до ПВЗ/двери, но не конкретные тариф/срок; [подробности](fpv-bench.md#уточнение-поставки-камеры-и-доставки). С этой альтернативой сумма пяти позиций 3 056 ₽, либо только антенна + камера 2 150 ₽, без доставки и возможного USB-кабеля. Подготовленная прошивка XIAO требует адаптации под Waveshare. Этот вариант не объявлен утверждённым заказом.

Пользователь подтвердил город получения — Чебоксары. Для ChipDip показан бесплатный привоз в местный магазин; для общего заказа срок и тариф курьера ещё пересчитать при оформлении, тарифы отдельных карточек не складывать. Привычная альтернатива камеры XIAO в ChipDip остаётся ниже, с долгим сроком и неподтверждённым OV3660. Серийную закупку камеры отложить до физического FPV-теста.

### Общая таблица кандидатов

Все ссылки в этой таблице ведут в российские магазины. «По карточке» означает показанный сайтом остаток, а не резерв или подтверждение заказа. Отдельные поисковые результаты оказались устаревшими; при расхождении использована открытая карточка/браузер.

| ID | Позиция и ссылка | Артикул магазина | Шт. на 1 / 4 / 6 | ₽ за единицу | ₽ на 1 / 4 / 6 | Наличие | Статус совместимости |
| --- | --- | --- | --- | ---: | --- | --- | --- |
| CTRL-01 | [ESP32-C3 SuperMini, Voltiq](https://voltiq.ru/shop/esp32-c3-supermini-dev-board/) | 17A-2 | 1 / 4 / 6 | 580 | 580 / 2 320 / 3 480 | Ожидается; браузер | Кандидат управления без камеры; ревизия, радиосвязь и посадка не проверены |
| STEER-01 | [SG90, позиционный 180°, YourDuino](https://www.yourduino.ru/product/servoprivod-sg90-180-grad-2) | C9-3001 | 1 / 4 / 6 | 240 | 240 / 960 / 1 440 | 150 по карточке | Класс серво из BOM zcar; размеры, люфт и ход проверить; вариант 360° не заменяет его |
| POWER-01 | [Mini360, Voltiq](https://voltiq.ru/shop/step-down-converter-mini360-dc-dc/) | 22A-7 | 1 / 4 / 6* | 136 | 136 / 544 / 816* | 77; браузер | Кандидат DC-DC, настроить и проверить нагрузку; «3 А» не принимать за доказанный длительный ток |
| CHARGE-01 | [IP2326, USB-C, 2S, PCUS](https://pcus.ru/moduli-pitaniya/plata-zaryada-s-zaschitoj-type-c-dlya-li-ion-batarej-2s) | 18650-2s | 1 / 4 / 6 | 160 | 160 / 640 / 960 | Есть; браузер, количество не указано | Только кандидат зарядника; ток и завершение заряда малой LiPo, балансировку и защиту проверить |
| USB-01 | [USB-C на плате, 8 выводов, Voltiq](https://voltiq.ru/shop/usb-type-c-dip-adapter-8-pin/) | 53C-6 | 1 / 4 / 6* | 75 | 75 / 300 / 450* | 114 по карточке | Заготовка для общего порта; не содержит зарядник, CC и распиновка не проверены |
| BEARING-01 | [625ZZ, 5 × 16 × 5 мм, AVRobot](https://www.avrobot.ru/product_info.php?products_id=2476) | 2476 | 4 / 16 / 24 | 25 | 100 / 400 / 600 | 251 по карточке | Размер из BOM zcar; посадки проверить на печати |
| CAM-01 | [ESP32-CAM + OV3660, YourDuino](https://www.yourduino.ru/product/modul-esp32-cam-s-kameroy-ov2640-1600x1200-66) | A0-07019 | 1 / 4 / 6** | 900 | 900 / 3 600 / 5 400 | 5; браузер, для 6 не хватает | Приоритетный сенсор для стенда, 30/60 FPS не подтверждены; программатор отдельно. Карточка противоречива, комплектацию проверить |

\* Число DC-DC и необходимость отдельного разъёма уточнятся после схемы: возможно разделение питания серво/камеры или использование разъёма контроллерной платы. Эти строки — сценарий расчёта, не указание соединить платы напрямую.

\** Если камера на каждой машине. Для K установленных камер считать K × цену камеры. Модули из разных магазинов не признаны одинаковыми ревизиями.

## Альтернативы, не суммировать с основной позицией

Для привода найдены два предложения привычного магазина; [проверка паспортов, передачи и ограничений](drive-candidates.md). На 1/4/6 комплектов «мотор + серво» — 236/944/1416 ₽, без силовой части и доставки. Серво заменяет STEER-01, а не добавляется вторым.

| ID | Деталь | ₽/шт. | Количество 1/4/6 | Сумма 1/4/6, ₽ | Наличие по карточке | Статус |
| --- | --- | ---: | --- | --- | --- | --- |
| MOTOR-CD-01 | [F130-08450 12.0V, ChipDip 9000145739](https://www.chipdip.ru/product/f130-08450-12.0v-elektrodvigatel-9000145739) | 66 | 1/4/6 | 66/264/396 | 117 шт. Москва, 3 дня | Диапазон 2,4–13,8 В включает 2S; медленный кандидат. Маркировка поставки, посадка, ток и тяга ещё не проверены |
| STEER-CD-01 | [SG90 180°, ChipDip 8009579822](https://www.chipdip.ru/product/servoprivod-tower-pro-sg90-180-s-neylonovym-reduktorom-8009579822) | 170 | 1/4/6 | 170/680/1020 | 179 шт. Москва, 5–8 дней | Аналоговый без подтверждённого бренда; образец для проверки размеров, питания, хода и люфта. Альтернатива STEER-01 |

Цены проверены 13 сентября в открытых карточках. Сроки отображены для Чебоксар; пользователь подтвердил этот город. Доставка отдельно; заказов нет. Эти позиции не добавлены автоматически в старую частичную сумму ниже.

Для питания 5 В добавлены альтернативы POWER-01; [сравнение, схема производителя и план нагрузочной проверки](drive-candidates.md#питание-5-в-от-имеющейся-2s). Waveshare остаётся необязательным стендовым кандидатом; после вопроса пользователя добавлено сравнение с имеющимся KIA7805API. Выбор для серии остаётся открытым.

| ID | Деталь | ₽/шт. | Сумма 1/4/6, ₽ без скидки | Наличие | Ограничения |
| --- | --- | ---: | --- | --- | --- |
| POWER-CD-01 | [TZT Mini360, 9002054616](https://www.chipdip.ru/product/mini360-adjustable-step-down-dc-dc-module-modul-tzt-9002054616) | 120 | 120/480/720 | 468 шт. Москва, 3 дня | 1,8 А по описанию, 3 А с охлаждением. Настроить выход; высота/нагрев/просадки не проверены |
| POWER-CD-02 | [Waveshare DC5-36-TO-DC3V3-5-M, 9001946092](https://www.chipdip.ru/product/dc5-36-to-dc3v3-5-m-dc-dc-preobrazovatel-waveshare-9001946092) | 670 | 670/2680/4020 | 22 шт. Москва, 3–5 дней | 5 В при входе от 6 В; свыше 3 А рекомендован теплоотвод. Версия с разъёмами, посадка не проверена |

Для каждой строки количество 1/4/6 плат. От 5 шт. текущая цена Mini360 — 101 ₽, Waveshare — 630 ₽: шесть плат со скидкой 606/3780 ₽. В CSV оставлены консервативные суммы по розничной цене. Это альтернативы, не два обязательных преобразователя на машину; в прежнюю частичную сумму ниже не включены. Доставка отдельно, заказов нет.

| Замена | ₽ | Наличие | Примечание |
| --- | ---: | --- | --- |
| CAM-S3-01: [XIAO ESP32S3 Sense, «Чип и Дип», 8061923216](https://www.chipdip.ru/product/113991115-development-boards-kits-arm-seeed-seeed-studio-8061923216) | 2 960 | 5054 шт. со сроком 7–8 недель по открытой карточке; не местный склад | Производитель 113991115. В карточке OV2640, поставка OV3660 не подтверждена. Резерв для одного стенда, серия не рассчитана. Доставка отдельно; [подробности](fpv-bench.md#проверка-привычных-площадок-после-подготовки-android-приёмника) |
| [ESP32-CAM + OV2640, ONPAD ESP32CAM](https://onpad.ru/catalog/cubie/module_esp/3375.html) | 1 090 | Есть по карточке; количество не указано | Прежний CAM-01, оставлен для сравнения с OV3660 |
| [M85K, MC002/FMC002, AliExpress 1005009992298687](https://aliexpress.ru/item/1005009992298687.html?sku_id=12000059797728061) | 832 за видимый вариант 10pcs | «99+» в открытом окне пользователя; склад РФ не подтверждён | Переходник micro-USB → USB-C, без зарядного контроллера. На фото разные исполнения; комплектность и посадку проверить. Доставка отдельно, видимый вариант от 162 ₽. Не суммировать с USB-01 |
| [ESP32-CAM + OV2640 с MicroUSB-программатором, YourDuino U7-07020](https://www.yourduino.ru/product/modul-esp32-cam-s-kameroy-ov2640-1600x1200-66-s-platoy-zagruzki-razem-microusb) | 1 620 за комплект | 28; браузер | Предложение для первого теста; вместо CAM-01. Цена 4 комплектов 6 480 ₽, 6 комплектов 9 720 ₽; программатор необязательно покупать на каждую машину |
| [Seeed XIAO ESP32S3 Sense, Amperkot 43119414](https://amperkot.ru/spb/catalog/seeed_studio_xiao_esp32s3_sense__miniatyurnaya_plata_s_kameroy_i_ai-43119414.html) | 2 900, последняя цена | Нет; браузер | Альтернатива паре контроллер + камера, требуется проверка GPIO и FPV. Зарядка 1S не подходит для 2S |
| [USB-C на плате, 4 вывода, Voltiq 43E-4](https://voltiq.ru/shop/usb-type-c-female-4-pin-connector/) | 73 | 158 по карточке | Вместо USB-01, если подтвердятся цепи CC и разводка |
| [IP2326, RoboShop 1011066](https://roboshop.spb.ru/modules/moduli-zaryada-akkumulyatorov/charge-type-c-2s) | 130 | Нет по карточке | Альтернативный поставщик зарядника |

## Остальные необходимые позиции

«—» означает, что цена/поставщик не выбраны; это **не нулевая стоимость**. Количество крепежа и геометрия взяты из [BOM автора zcar](https://github.com/alexyu132/zcar/blob/4b714e63fa30ed2030a8a48ab15f1e4a5fa380c4/README.md); при изменении CAD пересчитать.

| Позиция | Количество на 1 / 4 / 6 машинок | Цена/ссылка | Что нужно закрыть |
| --- | --- | --- | --- |
| Мотор 130 для 2S | 1 / 4 / 6 | Кандидат MOTOR-CD-01 выше, 66 ₽ | F130-08450 12 V: диапазон включает 8,4 В, но маркировка, тяга, ток и посадка полученного мотора требуют проверки. Мотор 130 на 3 В не равноценен |
| Коллекторный ESC с реверсом или собственный H-мост | 1 / 4 / 6 | — | Выбрать одну архитектуру по току мотора, габаритам и цене; имеющиеся TA6586 — экспериментальный запас |
| LW LiPo 601844HP, 2S, 600 мА·ч, 20C | Имеется 3; докупить 0 / 1 / 3 без дополнительных запасных | Цена дополнительных — | Основа задана пользователем. Габариты, состояние, разъёмы и ток заряда подтвердить; отсек zcar при необходимости адаптировать |
| Защита батареи / коммутация USB и батареи | 1 / 4 / 6 комплектов | — | Разрядный ток, отсечка, обратное питание, доступ к логике при зарядке |
| Шины 8,5 мм, наружный Ø25 / внутренний Ø20 мм | 4 / 16 / 24 | — | Поставщик одинаковой резины и твёрдости; соответствие печатным дискам |
| Винты M3 × 20, button head | 7 / 28 / 42 | — | Точная головка, фасовка и цена упаковки |
| Винты M3 × 14, button head | 2 / 8 / 12 | — | Точная головка, фасовка и цена упаковки |
| Винты M3 × 10, button head | 8 / 32 / 48 | — | Точная головка, фасовка и цена упаковки |
| Самоконтрящиеся гайки M3 с нейлоном | 17 / 68 / 102 | — | Габариты посадки, фасовка |
| Передние пружины, наружный Ø~4 мм, длина ~5 мм | 2 / 8 / 12 | — | Жёсткость и посадка |
| Задние пружины, наружный Ø~4 мм, длина ~22 мм | 2 / 8 / 12 | — | Жёсткость и посадка |
| Печать шасси, дисков и передачи | 1 / 4 / 6 комплектов | [Исходники](https://github.com/alexyu132/zcar) | Ревизия, материал, масса после слайсинга, цена печати и брака |
| Кузов и крепления камеры/электроники/USB | 1 / 4 / 6 комплектов | — | База кузова, обзор камеры, посадки и доступ к разъёму |
| Магниты кузова, направляющие и фиксатор батареи | 1 / 4 / 6 комплектов | — | Число и размер магнитов по CAD; независимая фиксация батареи, замена без инструмента. [Предложение](battery-and-body.md) |
| USB-C-подставка для зарядки снятого аккумулятора | На группу; число каналов открыто | — | Общая принадлежность для сменных батарей; зарядный узел и разъёмы пока не выбраны |
| Провода, разъёмы, выключатель, фильтрация, крепление плат | 1 / 4 / 6 комплектов | — | Состав по окончательной схеме и компоновке |
| USB-кабель с данными и подходящий сетевой адаптер | По сценарию зарядки | — | Зарядка всех одновременно или по очереди; доступный ток и работа C–C |
| Общий программатор, инструменты, точка доступа | На всю группу | — | Учитывать имеющиеся принадлежности; не умножать автоматически на число машин |

## Как читать стоимость

Арифметическая сумма шести строк CTRL-01…BEARING-01: **1 291 ₽ / 5 164 ₽ / 7 746 ₽** для 1/4/6 машин. С текущим CAM-01 (OV3660) на каждой: **2 191 ₽ / 8 764 ₽ / 13 146 ₽**. Расчёт на 6 арифметический: в карточке камеры только 5 штук.

Это только сумма найденной части деталей, включая контроллер, которого сейчас нет в наличии. Она не является ценой рабочей машинки: не учтены мотор, силовой драйвер, дополнительные батареи сверх имеющихся трёх, шины, крепёж, печать, кузов/магниты, зарядная подставка, обвязка питания и доставка. Вариант с прежним комплектом OV2640 за 1 620 ₽ даёт частичную сумму 2 911 ₽ для одной машины; это альтернатива, не текущий приоритет.

Для полной сметы нужно выбрать недостающие позиции, учесть упаковки (`округление вверх количества / фасовки`), доставку, общие принадлежности и запас. Батареи: докупить `max(0, число машин + число запасных − 3)` при исправности имеющихся. Скидки за количество пока не заложены.

Подробности выбора: [камера и FPV](camera-candidates.md), [USB-C и питание](usb-c-power.md), [контракты](contracts.md).

## Добавлено для имеющегося стенда

14 сентября: [порядок ближайшей закупки](aliexpress-shortlist.md#ближайшая-закупка-одного-экземпляра--14-сентября)
обновлён с учётом отсутствия антенны и подозрения на разряд батарейки DT838.
Нужна одна щелочная 6LR61 9 В для прибора (цену не подтвердили), затем один
образец камеры и деталей привода. Прежние цены четырёх карточек ChipDip
не удалось обновить из-за 403; они остаются снимком 13 сентября.

| ID | Деталь | Количество | Цена / предложение | Статус |
| --- | --- | --- | --- | --- |
| BENCH-ANT-01 | [RUICHI PCB P18 WIFI/2.4G IPEX-1 10cm](https://www.chipdip.ru/product/pcb-p18-wifi-2.4g-ipex-1-10cm-vnutrennyaya-ruichi-8030745314), артикул магазина 8030745314 | 1 для имеющегося стенда | 120 ₽, открытая карточка 13 сентября | Кандидат: 2400–2500 МГц, 50 Ом, IPEX-1, 27 × 7 мм, кабель 100 мм. По карточке 1 шт. на складе Москвы, срок 5 дней при выбранном регионе Чебоксары. Заявлено 5 dBi; это выше ориентира около 2 dBi и не утверждённая серийная антенна |

Параметры разъёма WROOM-32U: [Espressif, datasheet v2.7, §9.2](https://www.espressif.com/sites/default/files/documentation/esp32-wroom-32d_esp32-wroom-32u_datasheet_en.pdf). Характеристики P18 сверены с [производителем RUICHI, артикул 123656](https://ruichi.ru/antenny/antenny-wifi/vnutrenniaia-malogabaritnaia-wifi-antenna-ruichi-pcb-p18-2-4g-s-razemom-ipex-1-kleevoi-montazh-kabel-rg1-13-10sm-27x7-mm-5-dbi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). Совпадение частоты, сопротивления и семейства разъёма установлено; приём/передача на машине и реальное усиление не измерены. Не считать 5 dBi доказанным улучшением задержки и не объявлять эту антенну эквивалентом сертификационной антенны Espressif. MHF4 не подставлять вместо MHF I.

В карточке при выбранном регионе Чебоксары показан бесплатный привоз в магазин ориентировочно 18 сентября; Чебоксары подтверждены пользователем, заказ/резерв не оформлялись. Цена 120 ₽ не включает платную доставку. В частичные суммы целевой машины выше этот стендовый кандидат не включён; для 4–6 экземпляров текущего остатка недостаточно.

Ozon в браузере показал «Похоже, нет соединения», поисковые категории не дали проверенной карточки; AliExpress повторно не открывался из-за ранее подтверждённой капчи. «Чип и Дип» через обычный Chrome открылся, хотя веб-инструмент не смог прочитать его поиск. TX2400-FPC-5015 за 46 ₽ оказался позицией «доступно юр.лицам» и не выбран как простая покупка одного экземпляра.

Проект подключения имеющегося TA6586 и порядок проверки руля: [drive-bench.md](drive-bench.md). Перечень силовой обвязки там предварительный; полная закупка двигателя/серво зависит от осмотра K989 либо выбора отдельного привода.

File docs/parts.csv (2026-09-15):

ID | Деталь | Ссылка | Артикул | Количество_1 | Количество_4 | Количество_6 | Цена_РУБ | Стоимость_1 | Стоимость_4 | Стоимость_6 | Наличие | Совместимость | Дата_проверки
LOGIC-DIODE-02 | MAX40200AUK+T SOT23-5, ЧИП и ДИП | https://www.chipdip.ru/product/max40200auk-t-mikroshema-idealnyy-diod-s-sverhnizkim-maxim-9000587524 | 9000587524 | 1 | 4 | 6 | 50 | 50 | 200 | 300 | 97 шт. Москва, MOQ1, Чебоксары самовывоз ориентировочно 18 сентября бесплатно | Кандидат XIAO-LOGIC-01 v0.2 вместо LM66100. Не заказан. Это цена одного IC, не платы. Параметры SOT23 отличаются от WLP в заголовке. Переходы и PCB не проверены, PCN2571C не прочитан | 2026-09-15
CTRL-01 | ESP32-C3 SuperMini, Voltiq | https://voltiq.ru/shop/esp32-c3-supermini-dev-board/ | 17A-2 | 1 | 4 | 6 | 580 | 580 | 2320 | 3480 | Ожидается; браузер | Кандидат управления без камеры; ревизия, радиосвязь и посадка не проверены | 2026-09-13
STEER-01 | SG90, позиционный 180°, YourDuino | https://www.yourduino.ru/product/servoprivod-sg90-180-grad-2 | C9-3001 | 1 | 4 | 6 | 240 | 240 | 960 | 1440 | 150 по карточке | Класс серво из BOM zcar; размеры, люфт и ход проверить; вариант 360° не заменяет его | 2026-09-13
POWER-01 | Mini360, Voltiq | https://voltiq.ru/shop/step-down-converter-mini360-dc-dc/ | 22A-7 | 1 | 4 | 6 | 136 | 136 | 544 | 816 | 77; браузер | Кандидат DC-DC, настроить и проверить нагрузку; «3 А» не принимать за доказанный длительный ток | 2026-09-13
CHARGE-01 | IP2326, USB-C, 2S, PCUS | https://pcus.ru/moduli-pitaniya/plata-zaryada-s-zaschitoj-type-c-dlya-li-ion-batarej-2s | 18650-2s | 1 | 4 | 6 | 160 | 160 | 640 | 960 | Есть; браузер, количество не указано | Только кандидат зарядника; ток и завершение заряда малой LiPo, балансировку и защиту проверить | 2026-09-13
USB-01 | USB-C на плате, 8 выводов, Voltiq | https://voltiq.ru/shop/usb-type-c-dip-adapter-8-pin/ | 53C-6 | 1 | 4 | 6 | 75 | 75 | 300 | 450 | 114 по карточке | Заготовка для общего порта; не содержит зарядник, CC и распиновка не проверены | 2026-09-13
BEARING-01 | 625ZZ, 5 × 16 × 5 мм, AVRobot | https://www.avrobot.ru/product_info.php?products_id=2476 | 2476 | 4 | 16 | 24 | 25 | 100 | 400 | 600 | 251 по карточке | Размер из BOM zcar; посадки проверить на печати | 2026-09-13
CAM-01 | ESP32-CAM + OV3660, YourDuino | https://www.yourduino.ru/product/modul-esp32-cam-s-kameroy-ov2640-1600x1200-66 | A0-07019 | 1 | 4 | 6 | 900 | 900 | 3600 | 5400 | 5; браузер, для 6 не хватает | Приоритетный сенсор для стенда, 30/60 FPS не подтверждены; программатор отдельно. Карточка противоречива, комплектацию проверить | 2026-09-13
BENCH-ANT-01 | RUICHI PCB P18 WIFI/2.4G IPEX-1 10cm | https://www.chipdip.ru/product/pcb-p18-wifi-2.4g-ipex-1-10cm-vnutrennyaya-ruichi-8030745314 | 8030745314 | 1 |  |  | 120 | 120 |  |  | 1 шт. Москва, 5 дней для региона Чебоксары по карточке | Кандидат стенда 2.4 ГГц 50 Ом IPEX-1 27x7 мм кабель 100 мм. Заявленные 5 dBi выше ориентира 2 dBi. Для серии не выбран | 2026-09-13
CAM-S3-01 | Seeed XIAO ESP32S3 Sense, Чип и Дип | https://www.chipdip.ru/product/113991115-development-boards-kits-arm-seeed-seeed-studio-8061923216 | 8061923216 / 113991115 | 1 |  |  | 2960 | 2960 |  |  | 5054 шт. со сроком 7-8 недель по открытой карточке | Резервная альтернатива для стенда. В карточке OV2640, поставка OV3660 не подтверждена. Доставка отдельно. Не суммировать с CAM-01 | 2026-09-13
MOTOR-CD-01 | F130-08450 12.0V, Чип и Дип | https://www.chipdip.ru/product/f130-08450-12.0v-elektrodvigatel-9000145739 | 9000145739 | 1 | 4 | 6 | 66 | 66 | 264 | 396 | 117 шт. Москва, 3 дня для отображаемого региона Чебоксары | Кандидат 2S по диапазону 2.4-13.8 В. Маркировка поставки, посадка, ток и тяга не проверены. Доставка отдельно | 2026-09-13
STEER-CD-01 | SG90 180 градусов, Чип и Дип | https://www.chipdip.ru/product/servoprivod-tower-pro-sg90-180-s-neylonovym-reduktorom-8009579822 | 8009579822 | 1 | 4 | 6 | 170 | 170 | 680 | 1020 | 179 шт. Москва, 5-8 дней для отображаемого региона Чебоксары | Альтернатива STEER-01, не суммировать вместе. Аналоговый без подтвержденного бренда. Проверить питание, ход, ток, люфт и посадку | 2026-09-13
POWER-CD-01 | TZT Mini360, Чип и Дип | https://www.chipdip.ru/product/mini360-adjustable-step-down-dc-dc-module-modul-tzt-9002054616 | 9002054616 | 1 | 4 | 6 | 120 | 120 | 480 | 720 | 468 шт. Москва, 3 дня. От 5 шт. 101 руб., скидка в суммы не включена | Альтернатива POWER-01 или POWER-CD-02. До 1.8 А по описанию, 3 А с охлаждением. Настройка 5 В, просадки и нагрев не проверены | 2026-09-13
POWER-CD-02 | Waveshare DC5-36-TO-DC3V3-5-M, Чип и Дип | https://www.chipdip.ru/product/dc5-36-to-dc3v3-5-m-dc-dc-preobrazovatel-waveshare-9001946092 | 9001946092 / 29036 | 1 | 4 | 6 | 670 | 670 | 2680 | 4020 | 22 шт. Москва, 3-5 дней. От 5 шт. 630 руб., скидка в суммы не включена | Предложен для первого стенда вместо POWER-01. Режим 5 В требует вход от 6 В. Свыше 3 А рекомендовано охлаждение. Посадка версии с разъемами и нагрузка не проверены | 2026-09-13
CAM-WAV-01 | Waveshare ESP32-S3 с OV3660, Amperkot | https://amperkot.ru/products/aiot_plata_razrabotki_waveshare_na_baze_esp32s3_s_kameroy_ov3660/43150683.html | 43150683 | 1 |  |  | 2030 | 2030 |  |  | 2 шт. Москва, Санкт-Петербург нет. СДЭК до ПВЗ/двери, тариф и срок до пользователя не установлены | Резерв вне предпочтительных магазинов. Подтвердить SKU 33700 и Flash 8/16 МБ. Нужна адаптация прошивки Waveshare, FPV и посадка не проверены. Альтернатива CAM-01/CAM-S3-01 | 2026-09-13
CAM-ALI-05 | XIAO ESP32S3 Sense Solder - лот 5pcs, Your Cee | https://aliexpress.ru/item/1005008098777836.html?sku_id=12000058133585933 | 12000058133585933 | 1 |  |  | 7454 | 7454 |  |  | 99+ по карточке. ПВЗ Чебоксары бесплатно 24-30 сентября | Единица этой строки - лот 5pcs. Цена 1pc неизвестна. Продавец допускает OV2640 или OV3660. Не считать выбранным сенсором или закупленной серией | 2026-09-13
CONN-LOGIC-01 | Scondar SCT2505FH-02PL100 HK0083-0005 кабель SM 2 контакта одна половина | https://www.chipdip.ru/product/sct2505fh-02pl100-hk0083-0005-rozetka-razem-jst-scondar-9001071847 | 9001071847 | 1 | 4 | 6 | 86 | 86 | 344 | 516 | 892 шт. Москва, ориентир самовывоза Чебоксары 18 сентября бесплатно | Необязательная альтернатива припаянной паре DIRECT-LOGIC-HARNESS-01. Только половина на стороне H8/H3. Не заказан. 24AWG OD1.4мм 100±5мм по чертежу. Ответная половина, совместимость JST, новый маршрут и ток не проверены. Это не цена пары | 2026-09-15

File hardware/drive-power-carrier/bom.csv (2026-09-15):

reference | value | footprint | side | mpn_reference | status
C1 | 100n / 25V | RaceRemote_Motor:C_0805 | B |  | Candidate; not purchased
C2 | 470u / 16V | RaceRemote_Motor:CP_D8_P3.5 | F | 16ZLH470MEFC8X11.5 | Candidate; not purchased
C3 | 4.7u / 10V X7R | RaceRemote_DrivePower:C_0805_C3 | B |  | Candidate; not purchased
C4 | 4.7u / 10V X7R | RaceRemote_DrivePower:C_0805_C4 | B |  | Candidate; not purchased
C5 | 1u / 10V X7R | RaceRemote_DrivePower:C_0805_C5 | B |  | Candidate; not purchased
C6 | 1u / 10V X7R | RaceRemote_DrivePower:C_0805_C6 | B |  | Candidate; not purchased
H1 | CMD_FI | RaceRemote_Motor:WirePad_1mm | F |  | Integral PCB solder pad; not purchased connector
H10 | DRIVE_GND | RaceRemote_DrivePower:WirePad_1mm_H10 | F |  | Integral PCB solder pad; not purchased connector
H2 | CMD_BI | RaceRemote_Motor:WirePad_1mm | F |  | Integral PCB solder pad; not purchased connector
H3 | DRIVE_GND | RaceRemote_Motor:WirePad_1mm | F |  | Integral PCB solder pad; not purchased connector
H4 | VM | RaceRemote_Motor:WirePad_1mm | F |  | Integral PCB solder pad; not purchased connector
H5 | DRIVE_GND | RaceRemote_Motor:WirePad_1mm | F |  | Integral PCB solder pad; not purchased connector
H6 | FO | RaceRemote_Motor:WirePad_1mm | F |  | Integral PCB solder pad; not purchased connector
H7 | BO | RaceRemote_Motor:WirePad_1mm | F |  | Integral PCB solder pad; not purchased connector
H8 | WAVE_5V | RaceRemote_DrivePower:WirePad_1mm_H8 | F |  | Integral PCB solder pad; not purchased connector
H9 | XIAO_BAT | RaceRemote_DrivePower:WirePad_1mm_H9 | F |  | Integral PCB solder pad; not purchased connector
R1 | 100 / 1% | RaceRemote_Motor:R_0805 | F |  | Candidate; not purchased
R2 | 100 / 1% | RaceRemote_Motor:R_0805 | F |  | Candidate; not purchased
R3 | 10k / 1% | RaceRemote_Motor:R_0805 | F |  | Candidate; not purchased
R4 | 10k / 1% | RaceRemote_Motor:R_0805 | F |  | Candidate; not purchased
R5 | 23.2k / 0.1% | RaceRemote_DrivePower:R_0805_R5 | B |  | Candidate; not purchased
R6 | 10k / 0.1% | RaceRemote_DrivePower:R_0805_R6 | B |  | Candidate; not purchased
R7 | 360 / 1% / 0.25W | RaceRemote_DrivePower:R_1206_R7 | F |  | Candidate; not purchased
U1 | TA6586 DIP8 | RaceRemote_Motor:TA6586_DIP8 | F | TA6586 | Existing inventory
U2 | TPS73701DRBR | RaceRemote_DrivePower:TPS73701_DRB_3x3_EP_U2 | B | TPS73701DRBR | Candidate; not purchased
U3 | MAX40200AUK+T | RaceRemote_DrivePower:SOT23_5_ADI_90_0174_B_U3 | B | MAX40200AUK+T | Candidate; not purchased

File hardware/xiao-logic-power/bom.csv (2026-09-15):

reference | value | package_proposal | status | price_rub | price_checked | source_url
U1 | TPS73701DRBR | DRB VSON8 + EP, 3x3mm | Candidate, not purchased
U2 | MAX40200AUK+T | SOT23-5, not WLP / not TPMAX clone | Candidate, not purchased | 50 | 2026-09-15; MOQ1; Cheboksary pickup estimate 18 September | https://www.chipdip.ru/product/max40200auk-t-mikroshema-idealnyy-diod-s-sverhnizkim-maxim-9000587524
R1 | 23.2k / 0.1% | 0805 | Candidate, not purchased
R2 | 10k / 0.1% | 0805 | Candidate, not purchased
R3 | 360 / 1% / 0.25W | 1206, rating to verify | Candidate, not purchased
C1 | 4.7u / 10V X7R | 0805; effective C2>=1uF, C3/C4>=0.33uF | Candidate, not purchased
C2 | 4.7u / 10V X7R | 0805; effective C2>=1uF, C3/C4>=0.33uF | Candidate, not purchased
C3 | 1u / 10V X7R | 0805; effective C2>=1uF, C3/C4>=0.33uF | Candidate, not purchased
C4 | 1u / 10V X7R | 0805; effective C2>=1uF, C3/C4>=0.33uF | Candidate, not purchased
J1 | WAVE_5V |  | Logical interface, not purchased connector
J2 | DRIVE_GND |  | Logical interface, not purchased connector
J3 | XIAO_BAT |  | Logical interface, not purchased connector
J5 | DRIVE_GND |  | Logical interface, not purchased connector

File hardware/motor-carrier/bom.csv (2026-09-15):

reference | value | footprint | mpn_reference | status | price_rub
U1 | TA6586 DIP8 | RaceRemote_Motor:TA6586_DIP8 | TA6586 | Existing inventory
R1 | 100 / 1% | RaceRemote_Motor:R_0805 |  | Candidate, not purchased
R3 | 10k / 1% | RaceRemote_Motor:R_0805 |  | Candidate, not purchased
R2 | 100 / 1% | RaceRemote_Motor:R_0805 |  | Candidate, not purchased
R4 | 10k / 1% | RaceRemote_Motor:R_0805 |  | Candidate, not purchased
C1 | 100n / 25V | RaceRemote_Motor:C_0805 |  | Candidate, not purchased
C2 | 470u / 16V | RaceRemote_Motor:CP_D8_P3.5 | 16ZLH470MEFC8X11.5 | Candidate, not purchased
H1 | CMD_FI | RaceRemote_Motor:WirePad_1mm |  | Integral PCB solder pad, not a purchased connector
H2 | CMD_BI | RaceRemote_Motor:WirePad_1mm |  | Integral PCB solder pad, not a purchased connector
H3 | DRIVE_GND | RaceRemote_Motor:WirePad_1mm |  | Integral PCB solder pad, not a purchased connector
H4 | VM | RaceRemote_Motor:WirePad_1mm |  | Integral PCB solder pad, not a purchased connector
H5 | DRIVE_GND | RaceRemote_Motor:WirePad_1mm |  | Integral PCB solder pad, not a purchased connector
H6 | FO | RaceRemote_Motor:WirePad_1mm |  | Integral PCB solder pad, not a purchased connector
H7 | BO | RaceRemote_Motor:WirePad_1mm |  | Integral PCB solder pad, not a purchased connector

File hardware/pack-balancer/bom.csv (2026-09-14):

reference | value | purpose | footprint | selection
U801 | BQ29209DRBR | 4.30V secondary OVP and small balancing; NOT 4.2V charge regulation or primary BMS |  | Bench candidate, not ordered or physically qualified
R801 | 100 / 1% | Supply filter RVD, also upper balance path |  | Bench candidate, not ordered or physically qualified
R802 | 100 / 1% | Top sense filter, recommended 100..1000 ohm |  | Bench candidate, not ordered or physically qualified
R803 | 100 / 1% | Bottom sense filter, not internal switch resistance |  | Bench candidate, not ordered or physically qualified
R804 | 120 / 1% | RCB: use datasheet 7.6 guidance; not 250mA bypass |  | Bench candidate, not ordered or physically qualified
R805 | 100k / 1% | Default balance OFF; external sink must reference BAT_RAW_N |  | Bench candidate, not ordered or physically qualified
C801 | 100n / 16V | Local supply filter |  | Bench candidate, not ordered or physically qualified
C802 | 100n / 16V | Differential cell filter per Figure 9, NOT to ground |  | Bench candidate, not ordered or physically qualified
C803 | 100n / 16V | Bottom-cell filter |  | Bench candidate, not ordered or physically qualified
C804 | 100n / 16V / 10% | Nominal0.9s OVP delay, not full shutdown latency |  | Bench candidate, not ordered or physically qualified
J801 | CELL-SIDE BENCH NODES | Logical 2S emulator nodes only; not LW connector order; pin4 repeats raw negative |  | Bench candidate, not ordered or physically qualified
J802 | BATTERY-DOMAIN IO ONLY | No direct MCU/USB/permit wiring; level and ground crossing not designed |  | Bench candidate, not ordered or physically qualified

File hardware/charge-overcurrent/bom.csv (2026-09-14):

reference | value | purpose | footprint | selection
U701 | INA300AIDSQR | Always enabled and latched; no MCU clear/disable; not a current limiter |  | Candidate; no PCB or physical overcurrent qualification
C701 | 100n / 16V | Local bypass at VS |  | Candidate; no PCB or physical overcurrent qualification
R701 | 1.74k / 1% | Nominal 34.8mV threshold; 50us mode |  | Candidate; no PCB or physical overcurrent qualification
R702 | RL2512FK-070R1L | 0.1 ohm 1% 1W at70C +/-600ppm/C; two-terminal Kelvin layout required; placement pending |  | Candidate; no PCB or physical overcurrent qualification
J701 | FROM USB AUX | Not CHG_BIAS, XIAO or battery |  | Candidate; no PCB or physical overcurrent qualification
J702 | BENCH SERIES PATH | Positive charge flow pin1 to pin2; NOT actual battery connector or final BQ BAT/MID placement |  | Candidate; no PCB or physical overcurrent qualification
J703 | TO PERMIT J402 | Only existing R401 pulls up; no push-pull or second pull-up |  | Candidate; no PCB or physical overcurrent qualification

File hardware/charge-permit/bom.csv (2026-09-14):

reference | value | purpose | footprint | selection
U403 | TPS3808G33DBVR | SENSE=AUX; powered by independent CHG_BIAS_3V3; CT open |  | Candidate; footprints, qualified bias supply and physical qualification pending
U402 | SN74LVC2G17DCKR | Schmitt buffers for open-drain fault bus and ARM |  | Candidate; footprints, qualified bias supply and physical qualification pending
U401 | SN74LVC1G74DCTR | Positive-edge ARM, asynchronous fault clear; Q pin5 is permit |  | Candidate; footprints, qualified bias supply and physical qualification pending
U404 | TMUX1219DBVR | Q LOW selects bias (inhibit); Q HIGH selects ground |  | Candidate; footprints, qualified bias supply and physical qualification pending
U405 | TMUX1219DBVR | Fault LOW forces CD to bias independently of latch state |  | Candidate; footprints, qualified bias supply and physical qualification pending
U406 | TPS70933DBVR | Dedicated 3.3V bias, separate from AUX; EN intentionally floating |  | Candidate; footprints, qualified bias supply and physical qualification pending
C403 | 100n / 16V | Local IC bypass; place at corresponding IC |  | Candidate; footprints, qualified bias supply and physical qualification pending
C402 | 100n / 16V | Local IC bypass; place at corresponding IC |  | Candidate; footprints, qualified bias supply and physical qualification pending
C401 | 100n / 16V | Local IC bypass; place at corresponding IC |  | Candidate; footprints, qualified bias supply and physical qualification pending
C404 | 100n / 16V | Local TMUX bias bypass, not AUX |  | Candidate; footprints, qualified bias supply and physical qualification pending
C405 | 100n / 16V | Local TMUX bias bypass, not AUX |  | Candidate; footprints, qualified bias supply and physical qualification pending
R401 | 10k / 1% | Only pull-up for shared open-drain error bus |  | Candidate; footprints, qualified bias supply and physical qualification pending
R402 | 47k / 1% | ARM LOW with absent buffer; light load for MCU inverter |  | Candidate; footprints, qualified bias supply and physical qualification pending
R403 | 47k / 1% | Pull-down at VCC=0 only; not brownout proof |  | Candidate; footprints, qualified bias supply and physical qualification pending
R404 | 47k / 1% | Pull-up during switch transition; dynamic CD timing open |  | Candidate; footprints, qualified bias supply and physical qualification pending
R405 | 1M / 1% | Weak fault-bus pull-down; include in HIGH level budget |  | Candidate; footprints, qualified bias supply and physical qualification pending
C406 | 1u / 50V | Dedicated LDO input bypass |  | Candidate; footprints, qualified bias supply and physical qualification pending
C407 | 4.7u / 16V X7R | LDO output: effective 2.2..47uF total, ESR <=0.2ohm |  | Candidate; footprints, qualified bias supply and physical qualification pending
R406 | 3.3k / 1% | Approx 1mA preload; not an enforced current limit |  | Candidate; footprints, qualified bias supply and physical qualification pending
J401 | AUX AND CHARGER INPUT | AUX from U202; protected charger supply to U406; not raw USB, battery, REGN or another 3.3V rail |  | Candidate; footprints, qualified bias supply and physical qualification pending
J402 | FAULT SOURCES | External watchdog and OC: open drain only |  | Candidate; footprints, qualified bias supply and physical qualification pending
J403 | MCU INTERFACE | ARM edge, open-drain revoke/readback, Q observation |  | Candidate; footprints, qualified bias supply and physical qualification pending
J404 | TO BQ25887 CD | Active HIGH disable to BQ25887 pin3; signal only, no battery/traction current |  | Candidate; footprints, qualified bias supply and physical qualification pending

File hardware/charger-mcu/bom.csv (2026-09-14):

reference | value | purpose | footprint | selection
U601 | CH32V003F4P6 | USB source/charge MCU; GPIO names from allocation, no firmware yet |  | Candidate; firmware, PCB and electrical qualification pending
U602 | SN74LVC3G14DCTR | Three Schmitt inverters: released MCU pins default all requests LOW |  | Candidate; firmware, PCB and electrical qualification pending
R601 | 10k / 1% | Pull-up at inverter input; MCU open drain only |  | Candidate; firmware, PCB and electrical qualification pending
R602 | 10k / 1% | Pull-up at inverter input; MCU open drain only |  | Candidate; firmware, PCB and electrical qualification pending
R603 | 10k / 1% | Pull-up at inverter input; MCU open drain only |  | Candidate; firmware, PCB and electrical qualification pending
C601 | 100n / 16V | Local AUX bypass |  | Candidate; firmware, PCB and electrical qualification pending
C602 | 1u / 16V | Local AUX bypass |  | Candidate; firmware, PCB and electrical qualification pending
C603 | 100n / 16V | Local AUX bypass |  | Candidate; firmware, PCB and electrical qualification pending
R604 | 10k / 1% | Debug reset pull-up; NRST option bytes still required |  | Candidate; firmware, PCB and electrical qualification pending
J601 | FROM USB AUX | Only U202 AUX source; never parallel programmer supply |  | Candidate; firmware, PCB and electrical qualification pending
J602 | TO PERMIT J403 | Requires permit v0.4 R402=47k |  | Candidate; firmware, PCB and electrical qualification pending
J603 | TO WATCHDOG J502 | No watchdog disable connection |  | Candidate; firmware, PCB and electrical qualification pending
J604 | SOURCE POLICY | Request only; CC/brownout policy before SOURCE_ALLOW still required |  | Candidate; firmware, PCB and electrical qualification pending
J605 | TO BC J303 | No extra I2C or INT pull-ups |  | Candidate; firmware, PCB and electrical qualification pending
J606 | CC RESERVE | No raw CC pins; source detector interface pending |  | Candidate; firmware, PCB and electrical qualification pending
J607 | DEBUG LOGICAL | Not WCH-LinkE connector pinout; external-target power mode unverified |  | Candidate; firmware, PCB and electrical qualification pending
J608 | DIAGNOSTIC RESERVE | No raw battery or VBUS; divider/isolation not implemented |  | Candidate; firmware, PCB and electrical qualification pending

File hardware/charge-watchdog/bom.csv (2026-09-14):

reference | value | purpose | footprint | selection
U501 | TPS3431SDRBR | Always enabled, 170..230ms factory timeout; shared fault bus to permit latch |  | Candidate; no PCB or physical watchdog qualification
C501 | 100n / 16V | Local bypass at VDD |  | Candidate; no PCB or physical watchdog qualification
R501 | 10k / 1% | Factory 200ms selection; no capacitor on CWD |  | Candidate; no PCB or physical watchdog qualification
R502 | 47k / 1% | Default WDI LOW on MCU reset/disconnection |  | Candidate; no PCB or physical watchdog qualification
J501 | FROM USB AUX | Same AUX as MCU; not CHG_BIAS, XIAO or battery |  | Candidate; no PCB or physical watchdog qualification
J502 | FROM MCU | Falling edges from completed health-check loop; no autonomous PWM |  | Candidate; no PCB or physical watchdog qualification
J503 | TO PERMIT J402 | Open-drain combined WDO/ENOUT; only existing R401 pulls up |  | Candidate; no PCB or physical watchdog qualification

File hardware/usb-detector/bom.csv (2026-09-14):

reference | value | purpose | footprint | selection
U301 | PI3USB9201ZTAEX | BC1.2/legacy detector; charge-only sink, not a power source |  | Candidate; MCU, footprints and physical integration pending
C301 | 100n / 16V | Local bypass; included in total AUX load capacitance |  | Candidate; MCU, footprints and physical integration pending
R301 | 47k / 1% | Default detector disabled; MCU open drain sinks to enable |  | Candidate; MCU, footprints and physical integration pending
R302 | 4.7k / 1% | Single 3.3V I2C pull-up; 100kHz proposal |  | Candidate; MCU, footprints and physical integration pending
R303 | 4.7k / 1% | Single 3.3V I2C pull-up; no 5V MCU pull-ups |  | Candidate; MCU, footprints and physical integration pending
R304 | 10k / 1% | Active-low interrupt; not source permission |  | Candidate; MCU, footprints and physical integration pending
J301 | FROM USB AUX | 3.3V from TPS709 upstream of main gate; not battery or raw USB |  | Candidate; MCU, footprints and physical integration pending
J302 | USB PORT DATA | External connector D+/D- only; no CORE_DP/CORE_DM path |  | Candidate; MCU, footprints and physical integration pending
J303 | TO SOURCE MCU | Controller must also share J301 ground; no MCU or SOURCE_ALLOW generator implemented |  | Candidate; MCU, footprints and physical integration pending

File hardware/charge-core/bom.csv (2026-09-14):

reference | value | purpose | selection | footprint | price_rub | price_status
U101 | BQ25886RGER | Standalone boost charger; no cell balancing | Candidate; not purchased | Package_DFN_QFN:Texas_RGE0024H_VQFN-24-1EP_4x4mm_P0.5mm_EP2.7x2.7mm |  | not checked for this core BOM
C101 | 4.7u / 25V | VBUS; effective >=1uF | Candidate; not purchased |  |  | not checked for this core BOM
C102 | 22u / 25V | PMID input capacitance | Candidate; not purchased |  |  | not checked for this core BOM
C103 | 22u / 25V | PMID; input total effective >=10uF | Candidate; not purchased |  |  | not checked for this core BOM
L101 | 1uH | Boost inductor; saturation/ripple/MPN pending | Candidate; not purchased |  |  | not checked for this core BOM
C104 | 47u / 25V | SYS effective total C104+C105 >=44uF | Candidate; not purchased |  |  | not checked for this core BOM
C105 | 47u / 25V | SYS effective total C104+C105 >=44uF | Candidate; not purchased |  |  | not checked for this core BOM
C106 | 22u / 25V | BAT effective >=10uF at 8.4V | Candidate; not purchased |  |  | not checked for this core BOM
C107 | 10u / 16V | REGN effective >=4.7uF | Candidate; not purchased |  |  | not checked for this core BOM
C108 | 47n / 25V | Bootstrap: BTST to SW, never GND | Candidate; not purchased |  |  | not checked for this core BOM
R101 | 953 / 1% | Nominal 250mA study setting; not LW approval | Candidate; not purchased |  |  | not checked for this core BOM
R102 | 1.37k / 1% | Nominal input limit 810mA; not source qualification | Candidate; not purchased |  |  | not checked for this core BOM
R103 | 10k / 1% | Charge disabled unless external open drain sinks CE_N | Candidate; not purchased |  |  | not checked for this core BOM
R104 | 10k / 1% | 5V status pull-up; not directly 3.3V GPIO | Candidate; not purchased |  |  | not checked for this core BOM
R105 | 10k / 1% | 5V power-good pull-up; not charge permission | Candidate; not purchased |  |  | not checked for this core BOM
R106 | 5.23k / 1% | Reference thermistor divider upper leg | Candidate; not purchased |  |  | not checked for this core BOM
R107 | 30.1k / 1% | Lower leg in parallel with external 103AT-2 NTC | Candidate; not purchased |  |  | not checked for this core BOM
R108 | 0 | Local DCP configuration only; never connected to physical USB D+/D-. External source gate still required | Candidate; not purchased |  |  | not checked for this core BOM
J101 | QUALIFIED POWER ONLY | v0.2 power-only input from external source qualification; USB D+/D- are NOT routed into this core | Logical interface; connector and footprint TBD |  |  | not checked for this core BOM
J102 | PROTECTED CHARGE PATH | To separately designed cell protection; no raw LW connection authorized | Logical interface; connector and footprint TBD |  |  | not checked for this core BOM
J103 | EXTERNAL CHARGE GATE | Open drain CE plus 5V status; gate/level conversion not implemented | Logical interface; connector and footprint TBD |  |  | not checked for this core BOM
J104 | EXTERNAL NTC 103AT-2 | 10k thermistor at battery, not fixed resistor on controller | Logical interface; connector and footprint TBD |  |  | not checked for this core BOM

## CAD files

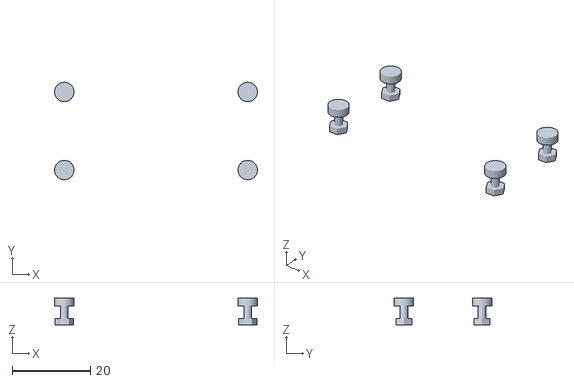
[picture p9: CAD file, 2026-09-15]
cad/packaging-v05/inputs/adjustable-main_fasteners.stl
52.0 x 25.0 x 6.90

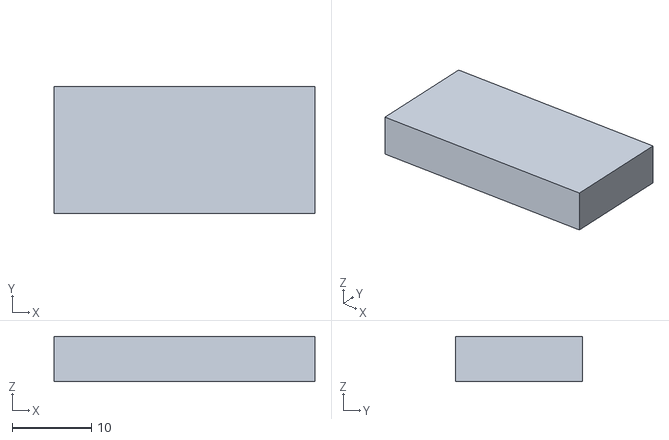
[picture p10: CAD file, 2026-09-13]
cad/components/buck-installed.stl
33.0 x 16.0 x 5.70

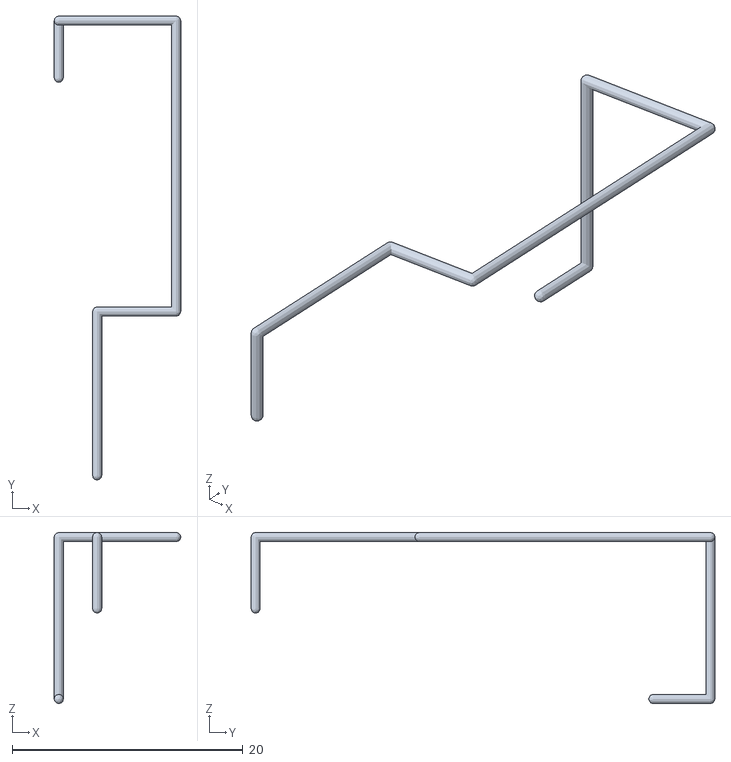
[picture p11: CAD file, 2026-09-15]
cad/control-harness/BI.stl
11.0 x 40.2 x 14.8

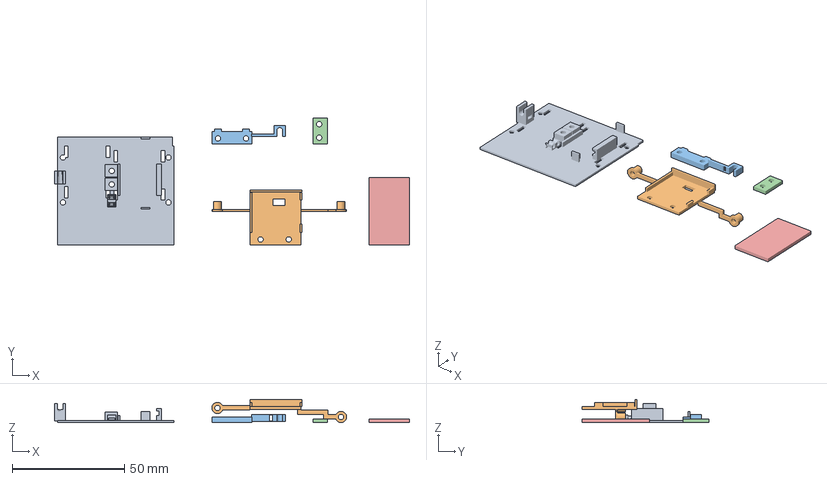
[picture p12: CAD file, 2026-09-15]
cad/current-fit-kit/electronics-fit.3mf
158.0 x 56.6 x 10.3 mm
tray
xiao_cradle
xiao_cap
pcb_clamp
pcb_gauge

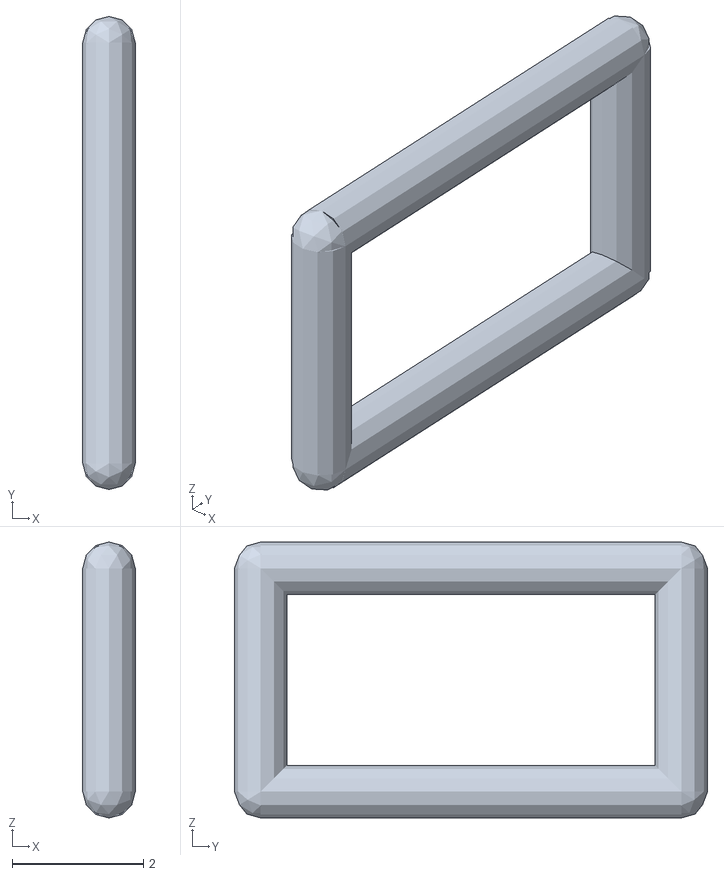
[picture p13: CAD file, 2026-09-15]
cad/direct-logic-harness/tie-space.stl
0.8 x 7.20 x 4.20

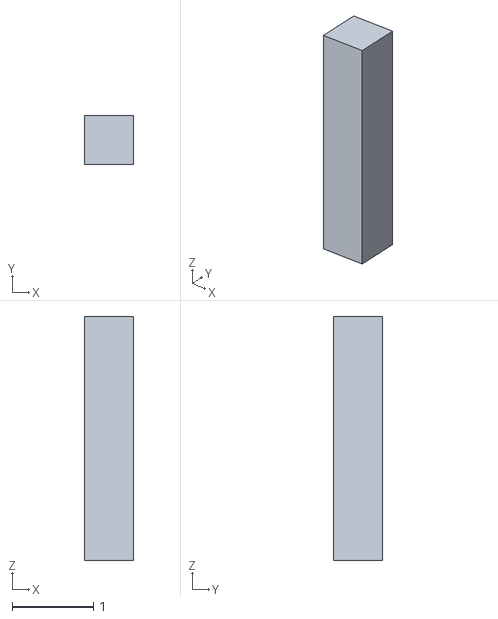
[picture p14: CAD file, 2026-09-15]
cad/drive-power-carrier/H10.stl
0.6 x 0.6 x 3.00

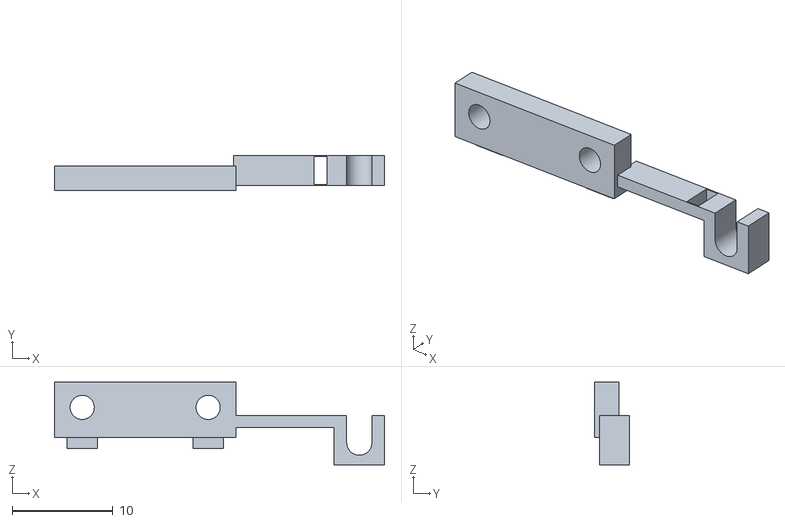
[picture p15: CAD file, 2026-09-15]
cad/harness-guides/cap.stl
32.8 x 3.50 x 8.20

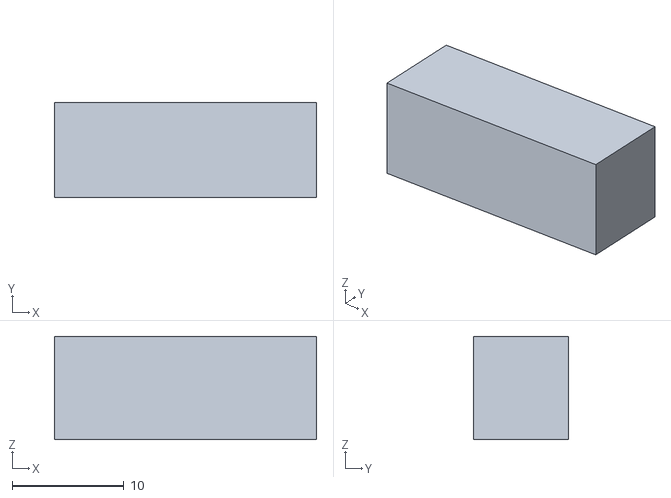
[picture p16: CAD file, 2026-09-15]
cad/logic-connector-study/sm-envelope.stl
23.4 x 8.50 x 9.20

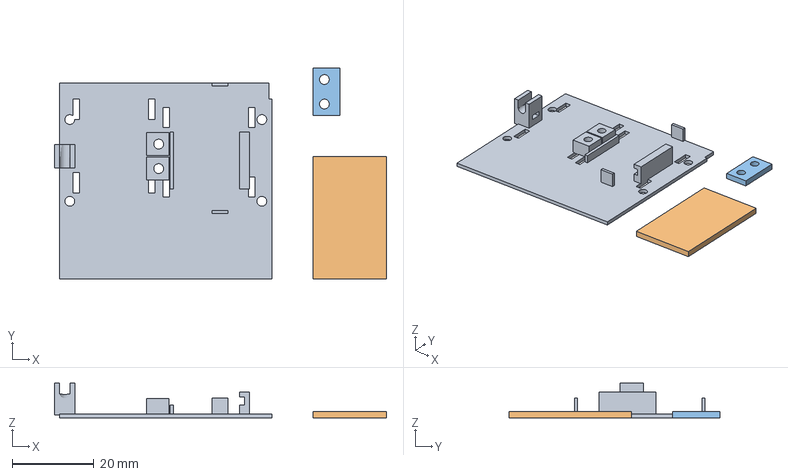
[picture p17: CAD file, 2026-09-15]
cad/motor-carrier-mount/print-kit.3mf
81.2 x 51.6 x 8.50 mm
tray
pcb_gauge
clamp

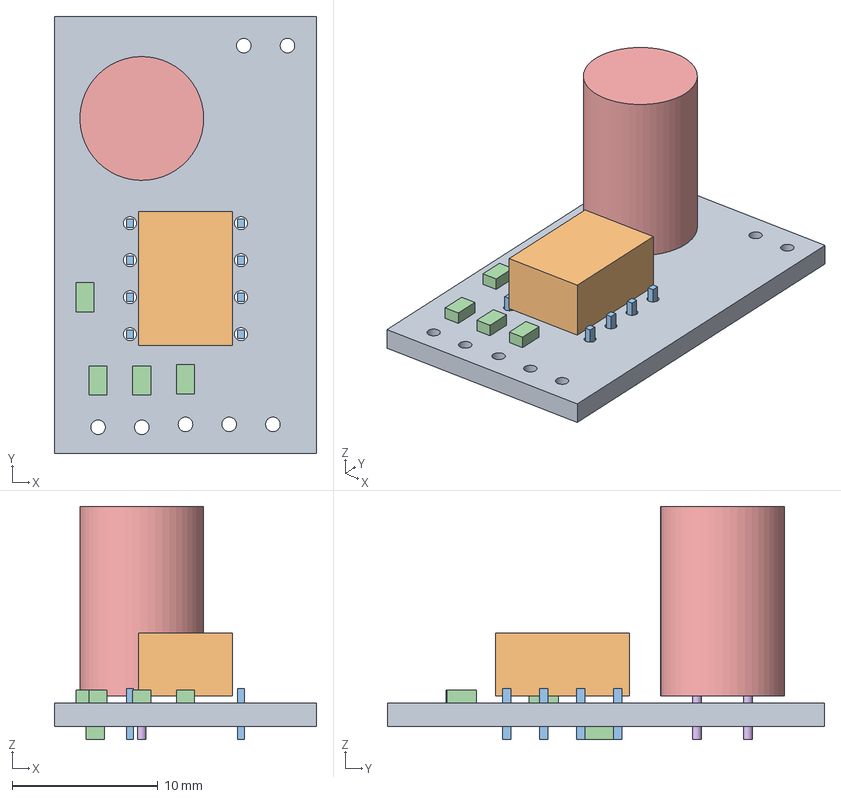
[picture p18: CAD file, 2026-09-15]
cad/motor-carrier/carrier.step
18.0 x 30.0 x 16.0 mm

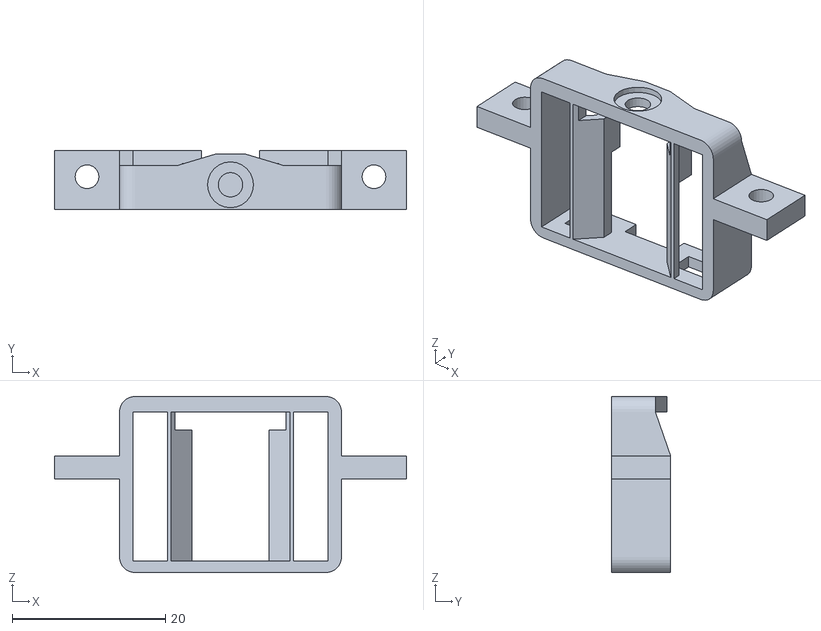
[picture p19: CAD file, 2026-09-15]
cad/motor-harness/reference-281.stl
46.0 x 7.75 x 23.0

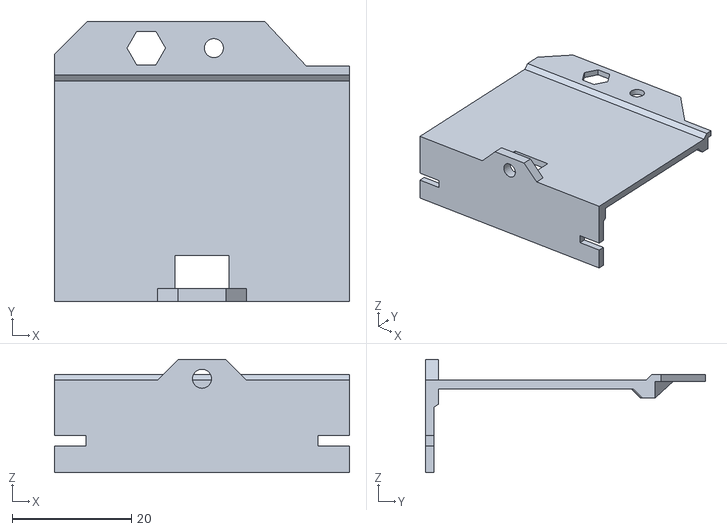
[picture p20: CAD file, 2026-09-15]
cad/packaging-v05/inputs/cover.stl
49.5 x 47.1 x 19.0

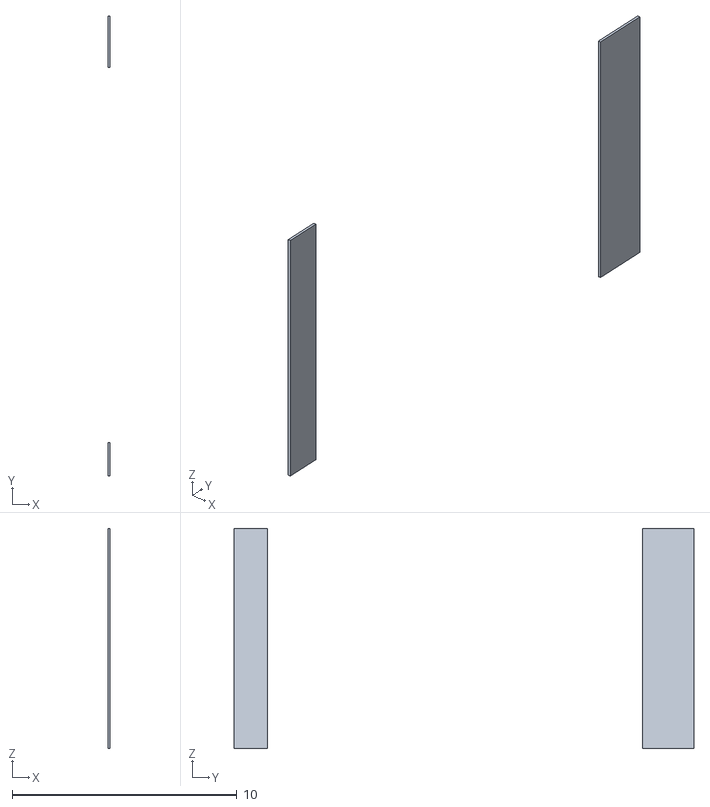
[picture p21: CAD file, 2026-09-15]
cad/packaging-v05/servo-frame-interference.stl
0.1 x 20.4 x 9.80

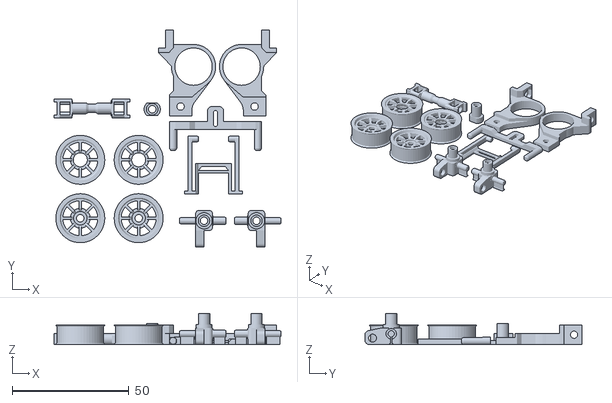
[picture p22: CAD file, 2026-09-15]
cad/reference/upstream-tray2.stl
97.2 x 93.1 x 13.4

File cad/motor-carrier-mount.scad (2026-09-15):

// MOTOR-MOUNT-01 v0.1. Candidate, mm; nominal electronics0/camera+3 only.
// Right fixed lip, left removable clamp. No threaded plastic holes.
use <harness-guides.scad>
part="assembly";
pcb_side_gap=.3;
pcb_top_gap=.3;
$fn=48;
module nut_pocket(x,y) {
    translate([x,y,27.6]) rotate([0,0,30]) cylinder(r=4.4/sqrt(3),h=1.8,$fn=6);
    // Slide the nut in from the left before fitting the neighbouring buck.
    // Hex across-corners span exceeds4mm across-flats: opening must clear it too.
    translate([19.8,y-2.55,27.6])cube([3.2,5.1,1.8]);
}
module holder() {
    difference() {
        union() {
            // Edge support at PCB underside Z29.5. Middle remains open for C1/tails.
            translate([25.75,52,27.2])cube([.9,14,2.3]);
            translate([42.8,52,27.2])cube([2.4,14,2.3]);
            // Candidate print clearances over nominal1.6 PCB; tune after gauge print.
            translate([43.75+pcb_side_gap,52,29.5])cube([1.45-pcb_side_gap,14,1.6+pcb_top_gap]);
            translate([42.8,52,31.1+pcb_top_gap])cube([2.4,14,1.2]);
            // Left nut towers, separated from PCB edge by .25.
            for(y=[57,63])translate([20, y-2.8,27.2])cube([5.5,5.6,3.9]);
            // Stops restrain fore/aft sliding on short, unpopulated edges.
            for(y=[46,77.2])translate([36, y,27.2])cube([4,.8,4]);
        }
        for(y=[57,63]) {
            translate([23,y,27])cylinder(d=2.4,h=5);
            nut_pocket(23,y);
        }
    }
}
module tray() {
    difference() {
        union(){tray_with_guide();holder();}
        // Continue screw clearance through the pre-existing tray floor.
        for(y=[57,63])translate([23,y,26])cylinder(d=2.4,h=7);
    }
}
module clamp() {
    difference() {
        translate([20.2,54.2,31.1])cube([6.6,11.6,1.6]);
        for(y=[57,63])translate([23,y,30.9])cylinder(d=2.4,h=2);
    }
}
module screws() {
    for(y=[57,63]) {
        // M2x6 under-head length; head envelope D3.8 x2, unthreaded CAD cylinder.
        translate([23,y,26.7])cylinder(d=2,h=6);
        translate([23,y,32.7])cylinder(d=3.8,h=2);
    }
}
module nuts() {
    for(y=[57,63])difference() {
        translate([23,y,27.7])rotate([0,0,30])cylinder(r=4/sqrt(3),h=1.6,$fn=6);
        translate([23,y,27.6])cylinder(d=2.0,h=1.8);
    }
}
module other_pads() {
    difference() {
        import("packaging-v05/pads.stl");
        translate([25,50,27])cube([19,23,2]);
    }
}
if(part=="holder")holder();
else if(part=="tray")tray();
else if(part=="clamp")clamp();
else if(part=="screws")screws();
else if(part=="nuts")nuts();
else if(part=="pads")other_pads();
else if(part=="tray_print")translate([2.5,-30,-26.3])tray();
else if(part=="clamp_print")translate([-20.2,-54.2,-31.1])clamp();
else if(part=="pcb_gauge_print")cube([18,30,1.6]);
else {
    color([.35,.65,.6])tray();
    color([1,.55,.15])clamp();
    color("silver"){screws();nuts();}
    %color([.15,.5,.3])import("motor-carrier/carrier.stl");
}

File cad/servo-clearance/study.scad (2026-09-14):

// Diagnostic reference only: no chassis modification or printable servo.
// See README.md and ../reference/NOTICE.md for source and evidence limits.
show_upstream=true;
show_candidate=true;
color([.65,.68,.7,.25]) import("frame.stl");
if(show_upstream) color([.2,.45,.8,.65]) import("upstream-servo.stl");
if(show_candidate) color([1,.65,.1,.15]) import("../components/servo-case-installed.stl");
color([.9,.1,.15]) import("interference.stl");

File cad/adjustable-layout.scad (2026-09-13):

// Adjustable packaging proposal 0.3; mm. NOT print-ready.
// Two independently clamped stages; adjust with the car powered off.
use <assembly.scad>
use <body-study.scad>
use <battery-holder.scad>
part="assembly";
electronics_slide=0; // Proposed nominal limits -3 .. +8 mm.
camera_slide=0;      // Same limits; compatible combinations checked separately.
$fn=48;

module slot(x,a,b) {
    hull() for(y=[a,b]) translate([x,y,23.8]) cylinder(h=2.4,r=1.2);
}
module fixed_base() {
    difference() {
        union() {
            envelope([60,48,2],[-5.25,40,24]);
            for(x=[4.25,39.25],y=[45,70]) envelope([6,6,5.75],[x,y,20.25]);
        }
        // Opening for the low independently movable camera support.
        envelope([28,17,3],[10.75,72,23.5]);
        for(x=[1.25,48.25]) { slot(x,46,57); slot(x,66,77); }
        for(x=[-2.75,52.25]) slot(x,75,86);
    }
}
module moving_tray() {
    translate([0,electronics_slide,0]) difference() {
        envelope([52,36,1],[-1.25,40,26.3]);
        for(x=[1.25,48.25],y=[49,69]) translate([x,y,26]) cylinder(h=2,r=1.2);
    }
}
module camera_stage() {
    translate([0,camera_slide,0]) difference() {
        union() {
            // Tabs carry two screws; bracket descends through the base opening.
            envelope([60,2,1],[-5.25,77,29.6]);
            for(x=[-2.75,52.25]) {
                translate([x,78,29.6]) cylinder(h=1,r=2.5);
                translate([x,78,26]) cylinder(h=3.6,r=1.8);
            }
            envelope([27,2,23],[11.25,77,21]);
            envelope([23,12,1],[13.25,79,21]);
        }
        // Keep central camera volume and upper bracket window clear.
        envelope([17,3,13],[16.25,76.5,28]);
        for(x=[-2.75,52.25]) translate([x,78,25.8]) cylinder(h=5,r=1.2);
    }
}
module screw_budget(x,y,head_z=27.3) {
    // M2-class space reservation, including nut/head; not a chosen SKU.
    translate([x,y,0]) union() {
        translate([0,0,22.4]) cylinder(h=head_z-22.4,r=1);
        translate([0,0,head_z]) cylinder(h=2,r=2.5);
        translate([0,0,22.4]) cylinder(h=1.6,r=2.31,$fn=6);
    }
}
module main_fasteners() {
    for(x=[1.25,48.25],y=[49,69]) screw_budget(x,y+electronics_slide);
}
module camera_fasteners() {
    for(x=[-2.75,52.25]) screw_budget(x,78+camera_slide,30.6);
}
module adjustable_camera() { envelope([23,12,21],[13.25,79+camera_slide,22]); }
module adjustable_driver() { envelope([30,18,10],[9.75,40+electronics_slide,27.6]); }
module adjustable_power() { envelope([33,16,5.7],[8.25,60+electronics_slide,27.6]); }
module adjustable_charge() { envelope([33,16,8],[8.25,60+electronics_slide,34.3]); }

if(part=="carrier_installed") fixed_base();
else if(part=="carrier_print") translate([5.25,-40,-20.25]) fixed_base();
else if(part=="tray") moving_tray();
else if(part=="camera_mount") camera_stage();
else if(part=="main_fasteners") main_fasteners();
else if(part=="camera_fasteners") camera_fasteners();
else if(part=="adhesive") adhesive_budget();
else if(part=="battery") battery_box();
else if(part=="power") adjustable_power();
else if(part=="camera") adjustable_camera();
else if(part=="driver") adjustable_driver();
else if(part=="charge") adjustable_charge();
else if(part=="body") body_shell();
else if(part=="cavity") body_volume(1);
else if(part=="assembly") {
    color([.55,.62,.67]) import("reference/zcar-aligned.stl");
    color("orange") battery_box();
    color("seagreen") support();
    color("purple") guards();
    color([.2,.2,.2]) band_corridor();
    color([.15,.65,.62]) fixed_base();
    color([.4,.8,.6]) moving_tray();
    color([.25,.6,.4]) camera_stage();
    color([.4,.4,.45]) { main_fasteners(); camera_fasteners(); }
    color([.95,.75,.15]) adjustable_power();
    color([.75,.2,.7]) adjustable_camera();
    color([.9,.3,.25]) adjustable_driver();
    color([.45,.35,.85]) adjustable_charge();
    color([.25,.45,.7,.18]) body_shell();
} else assert(false,"Unknown part");

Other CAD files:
cad/servo-bundle-study/bundle.stl
cad/servo-clearance/interference.stl
cad/servo-lacing/cord.stl
cad/servo-wiring/signal.stl
cad/assembly.scad
cad/adjustable-camera_mount.stl
cad/adjustable-layout-carrier.stl
cad/adjustable-tray.stl
cad/battery-dummy.stl
cad/battery-end-guard.stl
cad/battery-holder.scad
cad/battery-layout.scad
cad/battery-support.stl
cad/body-study-carrier.stl
cad/body-study.scad
cad/buck-output-harness/5V.stl
cad/buck-output-harness/GND.stl
cad/candidate-fit.scad
cad/components/bearing.stl
cad/components/buck.stl
cad/components/candidates.scad
cad/components/motor-installed.stl
cad/components/motor.stl
cad/components/motor_upper_case.stl
cad/components/servo-case-installed.stl
cad/components/servo_case.stl
cad/components/usb-port-pcb.scad
cad/components/xiao-sense-2023-installed.stl
cad/components/xiao-sense-2023.step
cad/components/zcar-without-reference-actuators.stl
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

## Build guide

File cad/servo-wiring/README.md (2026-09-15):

# Сигнал рулевого сервопривода

Следующий этап: [отдельная пара питания серво](../servo-power/README.md). Ниже сохранена проверка сигнала и исходное предложение источников питания.

15 сентября 2026. SERVO-WIRING-01 v0.1 — предложение проводки с проверкой геометрии. [Открыть сборку](viewer.html), [вид без кузова](overview.png), [расчёт](../../docs/evidence/servo-wiring-v01.json), [площадка D3](pad-reference.json). Продолжает [резерв жгута](../servo-bundle-study/README.md); его синий объём скрыт по умолчанию, чтобы был виден новый жёлтый провод.

Сигнал начинается на площадке **U9.4 / D3 / GPIO4** XIAO. Координаты извлечены из ранее зафиксированной PCB Seeed, а соответствие D3 → GPIO4 сверено с установленным Arduino variant и профилем прошивки. Перенос координат повторно проверен на прежних D0/D1/GND. Ревизия полученной платы пока неизвестна: производительский архив с именем v1.4 содержит PCB v1.5, а сборка использует STEP 2023 года.

Прямой выход от D3 вперёд пересекает плату расширения камеры на 0,600 мм³. Новый маршрут спускается под её нижний край, затем идёт к правому краю машины. Все 103 ограничивающих объёма XIAO оставлены целыми; срезана только задняя половина контактного конца провода на плоскости медной площадки Y83,25.

Предложен резерв Ø0,8 мм, длина оси **59,219 мм**. Это не выбранный провод и не длина для резки. Конечная точка X43,8/Y78/Z14 мм находится возле предполагаемого выхода кабеля серво; его настоящий выход, контакт разъёма, соединение с заводским проводом и разгрузка пайки ещё не определены. STL — отображение провода, не печатная деталь.

В номинальной позиции электроника 0 / камера +3 мм новый провод не пересекает проверенные препятствия и не выходит за условную полость кузова. Проверка обслуживания включает сигнал и прежний резерв жгута: 169 неподвижных объектов, 265 положений снятия кузова, 25 положений левого упора и непрерывный выход коробки батареи на 50 мм. Предполагаются выключенное питание, отсоединённые USB и аккумулятор, снятые кузов/лента/левый упор. Движение рулевого механизма и подвески, изгибы проводов и другие позиции электроники не проверены.

Прежний `bundle.stl` при повторной загрузке содержит вырожденные стыки. Для объёмной проверки обслуживания он **восстанавливается из ранее проверенных точек и радиуса**, а не автоматически ремонтируется. Его отображение остаётся прежним. Конфликты клеммы мотора A и старого силового коридора сохраняются; общий прототип физически не собран.

## Подключение питания — отдельное предложение

| Цепь серво | Предлагаемый источник | Статус |
| --- | --- | --- |
| Управляющий сигнал | XIAO D3 / GPIO4 | Начало в CAD привязано к площадке; вход серво приблизительный |
| Плюс питания | Waveshare VOUT, свободный P2.5 | Назначение для дальнейшей разводки; провод ещё не построен |
| Возврат тока | Waveshare GND, свободный P2.2 | Отдельный провод к преобразователю; ещё не построен |

По [схеме Waveshare](https://files.waveshare.com/wiki/DC5-36-TO-DC3V3-5/DC5-36-TO-DC3V3-5-Schematic.pdf), повторно прочитанной 15 сентября, P2.1–P2.3 — GND, P2.4–P2.6 — VOUT. Существующая пара логики занимает P2.3/P2.4; предложенная пара серво не дублирует их. Нумерация физических хвостов внутри каждой группы и посадка на полученном модуле ещё требуют сверки. P2.1/P2.6 остаются свободными. Возврат тока серво не проводится через XIAO GND0 или тонкий сигнальный провод; земли должны соответствовать [POWER-GROUND-01](../../docs/power-ground-domains.md), а не произвольно соединяться с сырым минусом LW.

Предлагается шина Waveshare 5 В; BAT0 XIAO, его 3,3 В и сырой 2S не являются питанием серво. [Waveshare указывает](https://www.waveshare.com/wiki/DC5-36-TO-DC3V3-5) вход от 6 В для режима 5 В и рекомендует дополнительное охлаждение при токе выше 3 А. Это не подтверждает тепловой режим под кузовом. [Страница TowerPro SG90 Digital](https://towerpro.com.tw/product/sg90-7/) указывает питание 4,8 В; ответ производителя на той же странице допускает 4,8–6 В и ориентировочно 0,5–2 А. Это сведения о конкретном изделии TowerPro, **не паспорт заказанного пользователем SG90 и не гарантированный пиковый ток**. Нагрузку серво и FPV на общий преобразователь предстоит измерить.

Уровень входа серво для 3,3 В, поведение при питании только XIAO от USB, возможное питание через сигнальный вход и последовательность включения остаются открытыми. Прямое соединение пока не квалифицировано электрически; буфер/защита при необходимости потребуют места и пересмотра маршрута. Частота и крайние импульсы берутся только из проверенной калибровки конкретного серво и тяги; новый CAD не меняет [SERVO-PWM-01](../../../RC_CAR_ESP32/docs/servo-outputs.md) и FAIL-01. Удаление импульсов не гарантирует обесточивание или центрирование колёс.

## Воспроизведение

Из корня, после подготовки прежней сборки:

```powershell
& build/tooling/kicad-10.0.6/bin/python.exe tools/extract_servo_pad.py
uv run --with-requirements tools/cad-candidate-requirements.txt python tools/build_servo_wiring.py
uv run --with-requirements tools/cad-candidate-requirements.txt python tools/build_servo_wiring_view.py
```

Исходники, координаты, SHA256 и геометрические результаты сохранены в JSON. [Проверка браузера](browser-check.json): 76 уникальных объектов, видимый сигнал, WebGL error 0; непроверенные регулировки скрыты. Экспорт canvas без кузова просмотрен, он не заменяет расчёт зазоров. Модели компонентов и их лицензии наследуются из [NOTICE](../packaging-v05/NOTICE.md). Печать, монтаж и прошивка в этой работе не выполнялись.

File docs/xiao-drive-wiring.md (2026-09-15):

# XIAO Sense: проект подключения привода 0.1

15 сентября: [отдельные провода FI/BI/GND и координаты площадок](../cad/control-harness/README.md) подготовлены в CAD для нового носителя TA6586 H1/H2/H3. Профиль D0/D1 сохранён; реальная пайка, уровень входов, фиксация проводов и силовая общая точка не проверены. Сопоставление PCB1.5 с STEP2023 не подтверждает ревизию купленной платы.

15 сентября: [кандидат серво и совместного управления](../../RC_CAR_ESP32/docs/servo-outputs.md)
подготовлен в прошивке `68a6cca`: D3/GPIO4, LOW_SPEED канал 4/таймер 2, 13 бит.
Калибровка частоты и крайних/центрального импульсов задаётся явно; тестовые значения
не являются профилем заказанного SG90. Код компилируется, но в main не создаётся
и к GPIO не подключён. Согласование общей частоты источника LEDC с камерой,
физические сигналы и рулевая механика ещё не проверены.

15 сентября: [подготовлен адаптер PWM](../../RC_CAR_ESP32/docs/motor-pwm.md)
для предложенных D0/D1, нативных низкоскоростных каналов LEDC 2/3 и таймера 1.
Он только компилируется, в основной программе не создаётся/не включается.
Частота мотора, сигнал/пределы серво, монтаж и совместная работа с камерой ещё
не проверены; эта карта остаётся предложением, а не подтверждённой проводкой.

14 сентября: общий [планировщик привода](drive-output-plan.md) добавлен в независимую задачу watchdog WROOM/XIAO. Рассчитывает ограниченный газ, нарастание, паузу реверса и ноль при отказах. Это ещё не аппаратный PWM/серво-драйвер; карта выводов ниже остаётся предложением без настройки GPIO. Для руля нет предположенных импульсов в микросекундах.

2026-09-13. DRIVE-01/STEER-01/POWER-01: **предложено, проводка не проверена**. Отдельная карта для найденного комплекта XIAO ESP32S3 Sense; прежние GPIO25/26/27 в drive-bench.md относятся только к WROOM. Камерные сборки используют общий [профиль платы](../../RC_CAR_ESP32/board/xiao_sense.h), но не настраивают выходы мотора или серво.

## Выводы и ресурсы

| Сигнал | Надпись XIAO | GPIO | Соединение после проверки монтажа |
| --- | --- | ---: | --- |
| Мотор FI | D0 | 1 | Через 100 Ом к TA6586, ножка 2; от входа 10 кОм к GND |
| Мотор BI | D1 | 2 | Через 100 Ом к TA6586, ножка 1; от входа 10 кОм к GND |
| Руль | D3 | 4 | Сигнальный вход позиционного серво после определения его распиновки и проверки уровня 3,3 В |
| Общая земля | GND | — | Силовая общая точка; ток мотора/серво не пропускать через провод земли XIAO |

Выводы сверены с [Seeed](https://wiki.seeedstudio.com/xiao_esp32s3_pin_multiplexing/) и `variants/XIAO_ESP32S3/pins_arduino.h` установленного Arduino ESP32 2.0.17. Камера использует GPIO10–18, 38–40, 47, 48; SD резервирует 7/8/9/21, микрофон 41/42. USB19/20, UART43/44, выводы загрузки 0/3/45/46 и память исключены из предложения. D2/GPIO3 оставлен свободным из-за функции strapping.

| Потребитель | Каналы LEDC Arduino 2.0.17 | Таймер | Статус |
| --- | --- | --- | --- |
| Камера XCLK | 0 | 0 | Уже используется, 20 МГц |
| Мотор FI/BI | 2 и 3 | 1 | Резерв; одна общая частота, ещё выбрать по испытанию моста |
| Серво | 4 | 2 | Резерв; частота и пределы импульсов по фактическому серво |

В закреплённом [Arduino ESP32 2.0.17](https://github.com/espressif/arduino-esp32/blob/2.0.17/cores/esp32/esp32-hal-ledc.c) номер таймера `(channel / 2) % 4`. Канал 1 делит таймер с камерой: настройка на частоту серво испортит XCLK даже при другом GPIO. Не использовать автоматически распределяющую каналы библиотеку серво без проверки её ресурсов. Профиль содержит статические проверки конфликтов и передаёт текущие номера камере; резерв не является реализацией PWM. При смене версии Arduino карту проверить заново.

## Первый стенд с раздельным питанием

```mermaid
flowchart LR
    USB[USB-C компьютера] --> X[XIAO Sense с камерой]
    B[LW 601844HP 2S] --> S[Выключатель и ограничение/защита после выбора]
    S --> T[TA6586 VCC 4]
    S --> P[Проверенный DC-DC 5 В]
    P --> R[Позиционный серво]
    X -->|D0 и D1 через входную обвязку| T
    X -->|D3 сигнал| R
    T -->|FO 5+6 и BO 7+8| M[Мотор]
    G[Общая точка GND] --- X
    G --- T
    G --- P
    G --- R
```

XIAO на этом этапе питается от USB; выход DC-DC питает только серво. Батарею 2S не подключать к BAT XIAO: [Seeed указывает для BAT 3,7 В](https://wiki.seeedstudio.com/xiao_esp32s3_getting_started/). Автономное питание XIAO и развязка сервисного USB остаются в [USB-C power](usb-c-power.md); текущее предложение использует отдельный зарядный порт. Мотор питается от моста, допустимость полного диапазона 2S для конкретной обмотки проверяется отдельно.

У моста резервируются 100 нФ и 470 мкФ/16 В между VCC и GND. Сначала выполнить [статический тест TA6586](ta6586-input-check.md) от ручных входов 3,3 В без мотора. Прежний расчёт VOH WROOM не является измерением выходов XIAO. Затем отдельно проверить питание и сигнал серво со снятой тягой. Его питание нельзя брать с 3V3 XIAO; цвета проводов не считаются доказательством распиновки.

## Остановка и остающиеся проверки

После проверки заводской схемы появился [вариант автономного питания со штатным USB-C](xiao-usb-power.md). Он использует отдельный DC-DC около 4,1 В через блокирующий диод к BAT0, при сохранении 5 В для серво. Этот вариант ещё не собран; приведённый выше первый стенд с отдельным питанием XIAO по USB остаётся исходной проверкой.

15 сентября подготовлена [альтернатива 0.2 от общего Waveshare 5 В](../hardware/xiao-logic-power/README.md): LDO около 4 В и MAX40200 с внутренней обратной блокировкой. Прежний провод сервисного VBUS удалён. Есть схема/ERC и DC-расчёт, но заметны потери/малый запас при просадке; переходы и теплоотвод не проверены. Это не утверждённая замена второго DC-DC и не инструкция включать привод.

Подтяжки FI/BI дают 00 при отключённых GPIO — отсутствие тяги и выбег, а не гарантированный короткий тормозной путь. Программный план уже обнуляется независимой задачей; ещё предстоит подключить к ней аппаратные выходы, выбрать выбег/электротормоз по току и пути остановки и проверить предложенные предел/нарастание/паузу реверса. Нельзя добавлять запись выходов только в сетевой цикл: при его задержке последний PWM продолжит работать. Отказ камеры не должен менять разрешение управления.

До включения GPIO нужны фактические соединения, уровни входов, питание/центр/пределы серво и проверенный способ ограничения тока первого включения. Затем — вывешенные колёса, потеря команд/сброс/отключение USB, совместная камера и нагрузка, после этого остановка на полу. Сейчас подтверждены только схема распределения ресурсов по документации и сборка, физические пункты не выполнены.

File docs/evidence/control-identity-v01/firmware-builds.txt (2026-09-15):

Processing esp32-bench (platform: espressif32@6.9.0; board: esp32dev; framework: arduino)

--------------------------------------------------------------------------------

Verbose mode can be enabled via `-v, --verbose` option

CONFIGURATION: https://docs.platformio.org/page/boards/espressif32/esp32dev.html

PLATFORM: Espressif 32 (6.9.0) > Espressif ESP32 Dev Module

HARDWARE: ESP32 240MHz, 320KB RAM, 4MB Flash

DEBUG: Current (cmsis-dap) External (cmsis-dap, esp-bridge, esp-prog, iot-bus-jtag, jlink, minimodule, olimex-arm-usb-ocd, olimex-arm-usb-ocd-h, olimex-arm-usb-tiny-h, olimex-jtag-tiny, tumpa)

PACKAGES: 

 - framework-arduinoespressif32 @ 3.20017.241212+sha.dcc1105b 

 - tool-esptoolpy @ 1.40501.0 (4.5.1) 

 - toolchain-xtensa-esp32 @ 8.4.0+2021r2-patch5

LDF: Library Dependency Finder -> https://bit.ly/configure-pio-ldf

LDF Modes: Finder ~ chain, Compatibility ~ soft

Found 34 compatible libraries

Scanning dependencies...

Dependency Graph

|-- WebSockets @ 2.6.1

|-- WebServer @ 2.0.0

|-- WiFi @ 2.0.0

|-- Ethernet @ 2.0.0

|-- SPI @ 2.0.0

|-- WiFiClientSecure @ 2.0.0

Building in release mode

Compiling .pio\build\esp32-bench\src\prototype\main.cpp.o

Compiling .pio\build\esp32-bench\src\prototype\motor_pwm_idf.cpp.o

Compiling .pio\build\esp32-bench\src\prototype\servo_pwm_idf.cpp.o

Building .pio\build\esp32-bench\bootloader.bin

Generating partitions .pio\build\esp32-bench\partitions.bin

esptool.py v4.5.1

Creating esp32 image...

Merged 1 ELF section

Successfully created esp32 image.

Compiling .pio\build\esp32-bench\libeb0\WiFi\WiFi.cpp.o

Compiling .pio\build\esp32-bench\libeb0\WiFi\WiFiAP.cpp.o

Compiling .pio\build\esp32-bench\libeb0\WiFi\WiFiClient.cpp.o

Compiling .pio\build\esp32-bench\libeb0\WiFi\WiFiGeneric.cpp.o

Compiling .pio\build\esp32-bench\libeb0\WiFi\WiFiMulti.cpp.o

Compiling .pio\build\esp32-bench\libeb0\WiFi\WiFiSTA.cpp.o

Compiling .pio\build\esp32-bench\libeb0\WiFi\WiFiScan.cpp.o

Compiling .pio\build\esp32-bench\libeb0\WiFi\WiFiServer.cpp.o

Compiling .pio\build\esp32-bench\libeb0\WiFi\WiFiUdp.cpp.o

Compiling .pio\build\esp32-bench\libd4a\Ethernet\ETH.cpp.o

Archiving .pio\build\esp32-bench\libeb0\libWiFi.a

Indexing .pio\build\esp32-bench\libeb0\libWiFi.a

Compiling .pio\build\esp32-bench\lib2d7\SPI\SPI.cpp.o

Compiling .pio\build\esp32-bench\lib081\WiFiClientSecure\WiFiClientSecure.cpp.o

Compiling .pio\build\esp32-bench\lib081\WiFiClientSecure\esp_crt_bundle.c.o

Compiling .pio\build\esp32-bench\lib081\WiFiClientSecure\ssl_client.cpp.o

Compiling .pio\build\esp32-bench\lib404\WebSockets\SocketIOclient.cpp.o

Compiling .pio\build\esp32-bench\lib404\WebSockets\WebSockets.cpp.o

Compiling .pio\build\esp32-bench\lib404\WebSockets\WebSocketsClient.cpp.o

Compiling .pio\build\esp32-bench\lib404\WebSockets\WebSocketsServer.cpp.o

Compiling .pio\build\esp32-bench\lib404\WebSockets\libb64\cdecode.c.o

Compiling .pio\build\esp32-bench\lib404\WebSockets\libb64\cencode.c.o

Compiling .pio\build\esp32-bench\lib404\WebSockets\libsha1\libsha1.c.o

Archiving .pio\build\esp32-bench\libd4a\libEthernet.a

Indexing .pio\build\esp32-bench\libd4a\libEthernet.a

Archiving .pio\build\esp32-bench\lib2d7\libSPI.a

Indexing .pio\build\esp32-bench\lib2d7\libSPI.a

Compiling .pio\build\esp32-bench\lib14a\FS\FS.cpp.o

Compiling .pio\build\esp32-bench\lib14a\FS\vfs_api.cpp.o

Compiling .pio\build\esp32-bench\lib2aa\WebServer\Parsing.cpp.o

Compiling .pio\build\esp32-bench\lib2aa\WebServer\WebServer.cpp.o

Compiling .pio\build\esp32-bench\lib2aa\WebServer\detail\mimetable.cpp.o

Compiling .pio\build\esp32-bench\FrameworkArduino\Esp.cpp.o

Archiving .pio\build\esp32-bench\lib404\libWebSockets.a

Archiving .pio\build\esp32-bench\lib081\libWiFiClientSecure.a

Compiling .pio\build\esp32-bench\FrameworkArduino\FirmwareMSC.cpp.o

Indexing .pio\build\esp32-bench\lib404\libWebSockets.a

Compiling .pio\build\esp32-bench\FrameworkArduino\FunctionalInterrupt.cpp.o

Indexing .pio\build\esp32-bench\lib081\libWiFiClientSecure.a

Compiling .pio\build\esp32-bench\FrameworkArduino\HWCDC.cpp.o

Compiling .pio\build\esp32-bench\FrameworkArduino\HardwareSerial.cpp.o

Compiling .pio\build\esp32-bench\FrameworkArduino\IPAddress.cpp.o

Compiling .pio\build\esp32-bench\FrameworkArduino\IPv6Address.cpp.o

Compiling .pio\build\esp32-bench\FrameworkArduino\MD5Builder.cpp.o

Compiling .pio\build\esp32-bench\FrameworkArduino\Print.cpp.o

Compiling .pio\build\esp32-bench\FrameworkArduino\Stream.cpp.o

Compiling .pio\build\esp32-bench\FrameworkArduino\StreamString.cpp.o

Archiving .pio\build\esp32-bench\lib14a\libFS.a

Indexing .pio\build\esp32-bench\lib14a\libFS.a

Compiling .pio\build\esp32-bench\FrameworkArduino\Tone.cpp.o

Compiling .pio\build\esp32-bench\FrameworkArduino\USB.cpp.o

Compiling .pio\build\esp32-bench\FrameworkArduino\USBCDC.cpp.o

Compiling .pio\build\esp32-bench\FrameworkArduino\USBMSC.cpp.o

Compiling .pio\build\esp32-bench\FrameworkArduino\WMath.cpp.o

Compiling .pio\build\esp32-bench\FrameworkArduino\WString.cpp.o

Compiling .pio\build\esp32-bench\FrameworkArduino\base64.cpp.o

Compiling .pio\build\esp32-bench\FrameworkArduino\cbuf.cpp.o

Compiling .pio\build\esp32-bench\FrameworkArduino\esp32-hal-adc.c.o

Compiling .pio\build\esp32-bench\FrameworkArduino\esp32-hal-bt.c.o

Archiving .pio\build\esp32-bench\lib2aa\libWebServer.a

Indexing .pio\build\esp32-bench\lib2aa\libWebServer.a

Compiling .pio\build\esp32-bench\FrameworkArduino\esp32-hal-cpu.c.o

Compiling .pio\build\esp32-bench\FrameworkArduino\esp32-hal-dac.c.o

Compiling .pio\build\esp32-bench\FrameworkArduino\esp32-hal-gpio.c.o

Compiling .pio\build\esp32-bench\FrameworkArduino\esp32-hal-i2c-slave.c.o

Compiling .pio\build\esp32-bench\FrameworkArduino\esp32-hal-i2c.c.o

Compiling .pio\build\esp32-bench\FrameworkArduino\esp32-hal-ledc.c.o

Compiling .pio\build\esp32-bench\FrameworkArduino\esp32-hal-matrix.c.o

Compiling .pio\build\esp32-bench\FrameworkArduino\esp32-hal-misc.c.o

Compiling .pio\build\esp32-bench\FrameworkArduino\esp32-hal-psram.c.o

Compiling .pio\build\esp32-bench\FrameworkArduino\esp32-hal-rgb-led.c.o

Compiling .pio\build\esp32-bench\FrameworkArduino\esp32-hal-rmt.c.o

Compiling .pio\build\esp32-bench\FrameworkArduino\esp32-hal-sigmadelta.c.o

Compiling .pio\build\esp32-bench\FrameworkArduino\esp32-hal-spi.c.o

Compiling .pio\build\esp32-bench\FrameworkArduino\esp32-hal-time.c.o

Compiling .pio\build\esp32-bench\FrameworkArduino\esp32-hal-timer.c.o

Compiling .pio\build\esp32-bench\FrameworkArduino\esp32-hal-tinyusb.c.o

Compiling .pio\build\esp32-bench\FrameworkArduino\esp32-hal-touch.c.o

Compiling .pio\build\esp32-bench\FrameworkArduino\esp32-hal-uart.c.o

Compiling .pio\build\esp32-bench\FrameworkArduino\firmware_msc_fat.c.o

Compiling .pio\build\esp32-bench\FrameworkArduino\libb64\cdecode.c.o

Compiling .pio\build\esp32-bench\FrameworkArduino\libb64\cencode.c.o

Compiling .pio\build\esp32-bench\FrameworkArduino\main.cpp.o

Compiling .pio\build\esp32-bench\FrameworkArduino\stdlib_noniso.c.o

Compiling .pio\build\esp32-bench\FrameworkArduino\wiring_pulse.c.o

Compiling .pio\build\esp32-bench\FrameworkArduino\wiring_shift.c.o

Archiving .pio\build\esp32-bench\libFrameworkArduino.a

Indexing .pio\build\esp32-bench\libFrameworkArduino.a

Linking .pio\build\esp32-bench\firmware.elf

Retrieving maximum program size .pio\build\esp32-bench\firmware.elf

Checking size .pio\build\esp32-bench\firmware.elf

Advanced Memory Usage is available via "PlatformIO Home > Project Inspect"

RAM:   [=         ]  14.4% (used 47044 bytes from 327680 bytes)

Flash: [======    ]  60.7% (used 795805 bytes from 1310720 bytes)

Building .pio\build\esp32-bench\firmware.bin

esptool.py v4.5.1

Creating esp32 image...

Merged 27 ELF sections

Successfully created esp32 image.

========================= [SUCCESS] Took 21.96 seconds =========================

Processing esp32-bench-sta (platform: espressif32@6.9.0; board: esp32dev; framework: arduino)

--------------------------------------------------------------------------------

Verbose mode can be enabled via `-v, --verbose` option

CONFIGURATION: https://docs.platformio.org/page/boards/espressif32/esp32dev.html

PLATFORM: Espressif 32 (6.9.0) > Espressif ESP32 Dev Module

HARDWARE: ESP32 240MHz, 320KB RAM, 4MB Flash

DEBUG: Current (cmsis-dap) External (cmsis-dap, esp-bridge, esp-prog, iot-bus-jtag, jlink, minimodule, olimex-arm-usb-ocd, olimex-arm-usb-ocd-h, olimex-arm-usb-tiny-h, olimex-jtag-tiny, tumpa)

PACKAGES: 

 - framework-arduinoespressif32 @ 3.20017.241212+sha.dcc1105b 

 - tool-esptoolpy @ 1.40501.0 (4.5.1) 

 - toolchain-xtensa-esp32 @ 8.4.0+2021r2-patch5

LDF: Library Dependency Finder -> https://bit.ly/configure-pio-ldf

LDF Modes: Finder ~ chain, Compatibility ~ soft

Found 34 compatible libraries

Scanning dependencies...

Dependency Graph

|-- WebSockets @ 2.6.1

|-- WebServer @ 2.0.0

|-- WiFi @ 2.0.0

|-- Ethernet @ 2.0.0

|-- SPI @ 2.0.0

|-- WiFiClientSecure @ 2.0.0

Building in release mode

Compiling .pio\build\esp32-bench-sta\src\prototype\main.cpp.o

Compiling .pio\build\esp32-bench-sta\src\prototype\motor_pwm_idf.cpp.o

Compiling .pio\build\esp32-bench-sta\src\prototype\servo_pwm_idf.cpp.o

Building .pio\build\esp32-bench-sta\bootloader.bin

Generating partitions .pio\build\esp32-bench-sta\partitions.bin

esptool.py v4.5.1

Creating esp32 image...

Merged 1 ELF section

Successfully created esp32 image.

Compiling .pio\build\esp32-bench-sta\libeb0\WiFi\WiFi.cpp.o

Compiling .pio\build\esp32-bench-sta\libeb0\WiFi\WiFiAP.cpp.o

Compiling .pio\build\esp32-bench-sta\libeb0\WiFi\WiFiClient.cpp.o

Compiling .pio\build\esp32-bench-sta\libeb0\WiFi\WiFiGeneric.cpp.o

Compiling .pio\build\esp32-bench-sta\libeb0\WiFi\WiFiMulti.cpp.o

Compiling .pio\build\esp32-bench-sta\libeb0\WiFi\WiFiSTA.cpp.o

Compiling .pio\build\esp32-bench-sta\libeb0\WiFi\WiFiScan.cpp.o

Compiling .pio\build\esp32-bench-sta\libeb0\WiFi\WiFiServer.cpp.o

Compiling .pio\build\esp32-bench-sta\libeb0\WiFi\WiFiUdp.cpp.o

Compiling .pio\build\esp32-bench-sta\libd4a\Ethernet\ETH.cpp.o

Compiling .pio\build\esp32-bench-sta\lib2d7\SPI\SPI.cpp.o

Compiling .pio\build\esp32-bench-sta\lib081\WiFiClientSecure\WiFiClientSecure.cpp.o

Compiling .pio\build\esp32-bench-sta\lib081\WiFiClientSecure\esp_crt_bundle.c.o

Compiling .pio\build\esp32-bench-sta\lib081\WiFiClientSecure\ssl_client.cpp.o

Compiling .pio\build\esp32-bench-sta\libc7f\WebSockets\SocketIOclient.cpp.o

Archiving .pio\build\esp32-bench-sta\libeb0\libWiFi.a

Compiling .pio\build\esp32-bench-sta\libc7f\WebSockets\WebSockets.cpp.o

Indexing .pio\build\esp32-bench-sta\libeb0\libWiFi.a

Compiling .pio\build\esp32-bench-sta\libc7f\WebSockets\WebSocketsClient.cpp.o

Compiling .pio\build\esp32-bench-sta\libc7f\WebSockets\WebSocketsServer.cpp.o

Compiling .pio\build\esp32-bench-sta\libc7f\WebSockets\libb64\cdecode.c.o

Compiling .pio\build\esp32-bench-sta\libc7f\WebSockets\libb64\cencode.c.o

Compiling .pio\build\esp32-bench-sta\libc7f\WebSockets\libsha1\libsha1.c.o

Compiling .pio\build\esp32-bench-sta\lib14a\FS\FS.cpp.o

Compiling .pio\build\esp32-bench-sta\lib14a\FS\vfs_api.cpp.o

Compiling .pio\build\esp32-bench-sta\lib2aa\WebServer\Parsing.cpp.o

Compiling .pio\build\esp32-bench-sta\lib2aa\WebServer\WebServer.cpp.o

Archiving .pio\build\esp32-bench-sta\lib2d7\libSPI.a

Archiving .pio\build\esp32-bench-sta\libd4a\libEthernet.a

Indexing .pio\build\esp32-bench-sta\lib2d7\libSPI.a

Indexing .pio\build\esp32-bench-sta\libd4a\libEthernet.a

Compiling .pio\build\esp32-bench-sta\lib2aa\WebServer\detail\mimetable.cpp.o

Compiling .pio\build\esp32-bench-sta\FrameworkArduino\Esp.cpp.o

Compiling .pio\build\esp32-bench-sta\FrameworkArduino\FirmwareMSC.cpp.o

Compiling .pio\build\esp32-bench-sta\FrameworkArduino\FunctionalInterrupt.cpp.o

Archiving .pio\build\esp32-bench-sta\lib081\libWiFiClientSecure.a

Compiling .pio\build\esp32-bench-sta\FrameworkArduino\HWCDC.cpp.o

Indexing .pio\build\esp32-bench-sta\lib081\libWiFiClientSecure.a

Compiling .pio\build\esp32-bench-sta\FrameworkArduino\HardwareSerial.cpp.o

Compiling .pio\build\esp32-bench-sta\FrameworkArduino\IPAddress.cpp.o

Compiling .pio\build\esp32-bench-sta\FrameworkArduino\IPv6Address.cpp.o

Compiling .pio\build\esp32-bench-sta\FrameworkArduino\MD5Builder.cpp.o

Compiling .pio\build\esp32-bench-sta\FrameworkArduino\Print.cpp.o

Compiling .pio\build\esp32-bench-sta\FrameworkArduino\Stream.cpp.o

Archiving .pio\build\esp32-bench-sta\libc7f\libWebSockets.a

Archiving .pio\build\esp32-bench-sta\lib14a\libFS.a

Indexing .pio\build\esp32-bench-sta\libc7f\libWebSockets.a

Indexing .pio\build\esp32-bench-sta\lib14a\libFS.a

Compiling .pio\build\esp32-bench-sta\FrameworkArduino\StreamString.cpp.o

Compiling .pio\build\esp32-bench-sta\FrameworkArduino\Tone.cpp.o

Compiling .pio\build\esp32-bench-sta\FrameworkArduino\USB.cpp.o

Compiling .pio\build\esp32-bench-sta\FrameworkArduino\USBCDC.cpp.o

Compiling .pio\build\esp32-bench-sta\FrameworkArduino\USBMSC.cpp.o

Archiving .pio\build\esp32-bench-sta\lib2aa\libWebServer.a

Compiling .pio\build\esp32-bench-sta\FrameworkArduino\WMath.cpp.o

Indexing .pio\build\esp32-bench-sta\lib2aa\libWebServer.a

Compiling .pio\build\esp32-bench-sta\FrameworkArduino\WString.cpp.o

Compiling .pio\build\esp32-bench-sta\FrameworkArduino\base64.cpp.o

Compiling .pio\build\esp32-bench-sta\FrameworkArduino\cbuf.cpp.o

Compiling .pio\build\esp32-bench-sta\FrameworkArduino\esp32-hal-adc.c.o

Compiling .pio\build\esp32-bench-sta\FrameworkArduino\esp32-hal-bt.c.o

Compiling .pio\build\esp32-bench-sta\FrameworkArduino\esp32-hal-cpu.c.o

Compiling .pio\build\esp32-bench-sta\FrameworkArduino\esp32-hal-dac.c.o

Compiling .pio\build\esp32-bench-sta\FrameworkArduino\esp32-hal-gpio.c.o

Compiling .pio\build\esp32-bench-sta\FrameworkArduino\esp32-hal-i2c-slave.c.o

Compiling .pio\build\esp32-bench-sta\FrameworkArduino\esp32-hal-i2c.c.o

Compiling .pio\build\esp32-bench-sta\FrameworkArduino\esp32-hal-ledc.c.o

Compiling .pio\build\esp32-bench-sta\FrameworkArduino\esp32-hal-matrix.c.o

Compiling .pio\build\esp32-bench-sta\FrameworkArduino\esp32-hal-misc.c.o

Compiling .pio\build\esp32-bench-sta\FrameworkArduino\esp32-hal-psram.c.o

Compiling .pio\build\esp32-bench-sta\FrameworkArduino\esp32-hal-rgb-led.c.o

Compiling .pio\build\esp32-bench-sta\FrameworkArduino\esp32-hal-rmt.c.o

Compiling .pio\build\esp32-bench-sta\FrameworkArduino\esp32-hal-sigmadelta.c.o

Compiling .pio\build\esp32-bench-sta\FrameworkArduino\esp32-hal-spi.c.o

Compiling .pio\build\esp32-bench-sta\FrameworkArduino\esp32-hal-time.c.o

Compiling .pio\build\esp32-bench-sta\FrameworkArduino\esp32-hal-timer.c.o

Compiling .pio\build\esp32-bench-sta\FrameworkArduino\esp32-hal-tinyusb.c.o

Compiling .pio\build\esp32-bench-sta\FrameworkArduino\esp32-hal-touch.c.o

Compiling .pio\build\esp32-bench-sta\FrameworkArduino\esp32-hal-uart.c.o

Compiling .pio\build\esp32-bench-sta\FrameworkArduino\firmware_msc_fat.c.o

Compiling .pio\build\esp32-bench-sta\FrameworkArduino\libb64\cdecode.c.o

Compiling .pio\build\esp32-bench-sta\FrameworkArduino\libb64\cencode.c.o

Compiling .pio\build\esp32-bench-sta\FrameworkArduino\main.cpp.o

Compiling .pio\build\esp32-bench-sta\FrameworkArduino\stdlib_noniso.c.o

Compiling .pio\build\esp32-bench-sta\FrameworkArduino\wiring_pulse.c.o

Compiling .pio\build\esp32-bench-sta\FrameworkArduino\wiring_shift.c.o

Archiving .pio\build\esp32-bench-sta\libFrameworkArduino.a

Indexing .pio\build\esp32-bench-sta\libFrameworkArduino.a

Linking .pio\build\esp32-bench-sta\firmware.elf

Retrieving maximum program size .pio\build\esp32-bench-sta\firmware.elf

Checking size .pio\build\esp32-bench-sta\firmware.elf

Advanced Memory Usage is available via "PlatformIO Home > Project Inspect"

RAM:   [=         ]  14.4% (used 47044 bytes from 327680 bytes)

Flash: [======    ]  60.7% (used 796161 bytes from 1310720 bytes)

Building .pio\build\esp32-bench-sta\firmware.bin

esptool.py v4.5.1

Creating esp32 image...

Merged 27 ELF sections

Successfully created esp32 image.

========================= [SUCCESS] Took 16.15 seconds =========================

Processing xiao-car-qvga (platform: espressif32@6.9.0; board: seeed_xiao_esp32s3; framework: arduino)

--------------------------------------------------------------------------------

Verbose mode can be enabled via `-v, --verbose` option

CONFIGURATION: https://docs.platformio.org/page/boards/espressif32/seeed_xiao_esp32s3.html

PLATFORM: Espressif 32 (6.9.0) > Seeed Studio XIAO ESP32S3

HARDWARE: ESP32S3 240MHz, 320KB RAM, 8MB Flash

DEBUG: Current (cmsis-dap) External (cmsis-dap, esp-bridge, esp-builtin, esp-prog, iot-bus-jtag, jlink, minimodule, olimex-arm-usb-ocd, olimex-arm-usb-ocd-h, olimex-arm-usb-tiny-h, olimex-jtag-tiny, tumpa)

PACKAGES: 

 - framework-arduinoespressif32 @ 3.20017.241212+sha.dcc1105b 

 - tool-esptoolpy @ 1.40501.0 (4.5.1) 

 - toolchain-riscv32-esp @ 8.4.0+2021r2-patch5 

 - toolchain-xtensa-esp32s3 @ 8.4.0+2021r2-patch5

LDF: Library Dependency Finder -> https://bit.ly/configure-pio-ldf

LDF Modes: Finder ~ chain, Compatibility ~ soft

Found 34 compatible libraries

Scanning dependencies...

Dependency Graph

|-- WebSockets @ 2.6.1

|-- WiFi @ 2.0.0

|-- WebServer @ 2.0.0

|-- Ethernet @ 2.0.0

|-- SPI @ 2.0.0

|-- WiFiClientSecure @ 2.0.0

Building in release mode

Compiling .pio\build\xiao-car-qvga\src\camera\main.cpp.o

Compiling .pio\build\xiao-car-qvga\src\prototype\main.cpp.o

Compiling .pio\build\xiao-car-qvga\src\prototype\motor_pwm_idf.cpp.o

Compiling .pio\build\xiao-car-qvga\src\prototype\servo_pwm_idf.cpp.o

Building .pio\build\xiao-car-qvga\bootloader.bin

Generating partitions .pio\build\xiao-car-qvga\partitions.bin

esptool.py v4.5.1

Creating esp32s3 image...

Merged 1 ELF section

Successfully created esp32s3 image.

Compiling .pio\build\xiao-car-qvga\libeb0\WiFi\WiFi.cpp.o

Compiling .pio\build\xiao-car-qvga\libeb0\WiFi\WiFiAP.cpp.o

Compiling .pio\build\xiao-car-qvga\libeb0\WiFi\WiFiClient.cpp.o

Compiling .pio\build\xiao-car-qvga\libeb0\WiFi\WiFiGeneric.cpp.o

Compiling .pio\build\xiao-car-qvga\libeb0\WiFi\WiFiMulti.cpp.o

Compiling .pio\build\xiao-car-qvga\libeb0\WiFi\WiFiSTA.cpp.o

Compiling .pio\build\xiao-car-qvga\libeb0\WiFi\WiFiScan.cpp.o

Compiling .pio\build\xiao-car-qvga\libeb0\WiFi\WiFiServer.cpp.o

Compiling .pio\build\xiao-car-qvga\libeb0\WiFi\WiFiUdp.cpp.o

Compiling .pio\build\xiao-car-qvga\libd4a\Ethernet\ETH.cpp.o

Compiling .pio\build\xiao-car-qvga\lib2d7\SPI\SPI.cpp.o

Compiling .pio\build\xiao-car-qvga\lib081\WiFiClientSecure\WiFiClientSecure.cpp.o

Compiling .pio\build\xiao-car-qvga\lib081\WiFiClientSecure\esp_crt_bundle.c.o

Compiling .pio\build\xiao-car-qvga\lib081\WiFiClientSecure\ssl_client.cpp.o

Compiling .pio\build\xiao-car-qvga\lib2cf\WebSockets\SocketIOclient.cpp.o

Compiling .pio\build\xiao-car-qvga\lib2cf\WebSockets\WebSockets.cpp.o

Compiling .pio\build\xiao-car-qvga\lib2cf\WebSockets\WebSocketsClient.cpp.o

Compiling .pio\build\xiao-car-qvga\lib2cf\WebSockets\WebSocketsServer.cpp.o

Compiling .pio\build\xiao-car-qvga\lib2cf\WebSockets\libb64\cdecode.c.o

Compiling .pio\build\xiao-car-qvga\lib2cf\WebSockets\libb64\cencode.c.o

Archiving .pio\build\xiao-car-qvga\libeb0\libWiFi.a

Indexing .pio\build\xiao-car-qvga\libeb0\libWiFi.a

Archiving .pio\build\xiao-car-qvga\libd4a\libEthernet.a

Indexing .pio\build\xiao-car-qvga\libd4a\libEthernet.a

Compiling .pio\build\xiao-car-qvga\lib2cf\WebSockets\libsha1\libsha1.c.o

Compiling .pio\build\xiao-car-qvga\lib14a\FS\FS.cpp.o

Archiving .pio\build\xiao-car-qvga\lib2d7\libSPI.a

Indexing .pio\build\xiao-car-qvga\lib2d7\libSPI.a

Compiling .pio\build\xiao-car-qvga\lib14a\FS\vfs_api.cpp.o

Compiling .pio\build\xiao-car-qvga\lib2aa\WebServer\Parsing.cpp.o

Compiling .pio\build\xiao-car-qvga\lib2aa\WebServer\WebServer.cpp.o

Compiling .pio\build\xiao-car-qvga\lib2aa\WebServer\detail\mimetable.cpp.o

Compiling .pio\build\xiao-car-qvga\FrameworkArduino\Esp.cpp.o

Archiving .pio\build\xiao-car-qvga\lib081\libWiFiClientSecure.a

Archiving .pio\build\xiao-car-qvga\lib2cf\libWebSockets.a

Compiling .pio\build\xiao-car-qvga\FrameworkArduino\FirmwareMSC.cpp.o

Compiling .pio\build\xiao-car-qvga\FrameworkArduino\FunctionalInterrupt.cpp.o

Compiling .pio\build\xiao-car-qvga\FrameworkArduino\HWCDC.cpp.o

Indexing .pio\build\xiao-car-qvga\lib081\libWiFiClientSecure.a

Indexing .pio\build\xiao-car-qvga\lib2cf\libWebSockets.a

Compiling .pio\build\xiao-car-qvga\FrameworkArduino\HardwareSerial.cpp.o

Compiling .pio\build\xiao-car-qvga\FrameworkArduino\IPAddress.cpp.o

Compiling .pio\build\xiao-car-qvga\FrameworkArduino\IPv6Address.cpp.o

Compiling .pio\build\xiao-car-qvga\FrameworkArduino\MD5Builder.cpp.o

Compiling .pio\build\xiao-car-qvga\FrameworkArduino\Print.cpp.o

Archiving .pio\build\xiao-car-qvga\lib14a\libFS.a

Compiling .pio\build\xiao-car-qvga\FrameworkArduino\Stream.cpp.o

Indexing .pio\build\xiao-car-qvga\lib14a\libFS.a

Compiling .pio\build\xiao-car-qvga\FrameworkArduino\StreamString.cpp.o

Compiling .pio\build\xiao-car-qvga\FrameworkArduino\Tone.cpp.o

Compiling .pio\build\xiao-car-qvga\FrameworkArduino\USB.cpp.o

Archiving .pio\build\xiao-car-qvga\lib2aa\libWebServer.a

Compiling .pio\build\xiao-car-qvga\FrameworkArduino\USBCDC.cpp.o

Compiling .pio\build\xiao-car-qvga\FrameworkArduino\USBMSC.cpp.o

Compiling .pio\build\xiao-car-qvga\FrameworkArduino\WMath.cpp.o

Compiling .pio\build\xiao-car-qvga\FrameworkArduino\WString.cpp.o

Compiling .pio\build\xiao-car-qvga\FrameworkArduino\base64.cpp.o

Compiling .pio\build\xiao-car-qvga\FrameworkArduino\cbuf.cpp.o

Indexing .pio\build\xiao-car-qvga\lib2aa\libWebServer.a

Compiling .pio\build\xiao-car-qvga\FrameworkArduino\esp32-hal-adc.c.o

Compiling .pio\build\xiao-car-qvga\FrameworkArduino\esp32-hal-bt.c.o

Compiling .pio\build\xiao-car-qvga\FrameworkArduino\esp32-hal-cpu.c.o

Compiling .pio\build\xiao-car-qvga\FrameworkArduino\esp32-hal-dac.c.o

Compiling .pio\build\xiao-car-qvga\FrameworkArduino\esp32-hal-gpio.c.o

Compiling .pio\build\xiao-car-qvga\FrameworkArduino\esp32-hal-i2c-slave.c.o

Compiling .pio\build\xiao-car-qvga\FrameworkArduino\esp32-hal-i2c.c.o

Compiling .pio\build\xiao-car-qvga\FrameworkArduino\esp32-hal-ledc.c.o

Compiling .pio\build\xiao-car-qvga\FrameworkArduino\esp32-hal-matrix.c.o

Compiling .pio\build\xiao-car-qvga\FrameworkArduino\esp32-hal-misc.c.o

Compiling .pio\build\xiao-car-qvga\FrameworkArduino\esp32-hal-psram.c.o

Compiling .pio\build\xiao-car-qvga\FrameworkArduino\esp32-hal-rgb-led.c.o

Compiling .pio\build\xiao-car-qvga\FrameworkArduino\esp32-hal-rmt.c.o

Compiling .pio\build\xiao-car-qvga\FrameworkArduino\esp32-hal-sigmadelta.c.o

Compiling .pio\build\xiao-car-qvga\FrameworkArduino\esp32-hal-spi.c.o

Compiling .pio\build\xiao-car-qvga\FrameworkArduino\esp32-hal-time.c.o

Compiling .pio\build\xiao-car-qvga\FrameworkArduino\esp32-hal-timer.c.o

Compiling .pio\build\xiao-car-qvga\FrameworkArduino\esp32-hal-tinyusb.c.o

Compiling .pio\build\xiao-car-qvga\FrameworkArduino\esp32-hal-touch.c.o

Compiling .pio\build\xiao-car-qvga\FrameworkArduino\esp32-hal-uart.c.o

Compiling .pio\build\xiao-car-qvga\FrameworkArduino\firmware_msc_fat.c.o

Compiling .pio\build\xiao-car-qvga\FrameworkArduino\libb64\cdecode.c.o

Compiling .pio\build\xiao-car-qvga\FrameworkArduino\libb64\cencode.c.o

Compiling .pio\build\xiao-car-qvga\FrameworkArduino\main.cpp.o

Compiling .pio\build\xiao-car-qvga\FrameworkArduino\stdlib_noniso.c.o

Compiling .pio\build\xiao-car-qvga\FrameworkArduino\wiring_pulse.c.o

Compiling .pio\build\xiao-car-qvga\FrameworkArduino\wiring_shift.c.o

Archiving .pio\build\xiao-car-qvga\libFrameworkArduino.a

Indexing .pio\build\xiao-car-qvga\libFrameworkArduino.a

Linking .pio\build\xiao-car-qvga\firmware.elf

Retrieving maximum program size .pio\build\xiao-car-qvga\firmware.elf

Checking size .pio\build\xiao-car-qvga\firmware.elf

Advanced Memory Usage is available via "PlatformIO Home > Project Inspect"

RAM:   [==        ]  15.5% (used 50824 bytes from 327680 bytes)

Flash: [==        ]  24.7% (used 827029 bytes from 3342336 bytes)

Building .pio\build\xiao-car-qvga\firmware.bin

esptool.py v4.5.1

Creating esp32s3 image...

Merged 2 ELF sections

Successfully created esp32s3 image.

========================= [SUCCESS] Took 22.73 seconds =========================

Processing xiao-car-vga (platform: espressif32@6.9.0; board: seeed_xiao_esp32s3; framework: arduino)

--------------------------------------------------------------------------------

Verbose mode can be enabled via `-v, --verbose` option

CONFIGURATION: https://docs.platformio.org/page/boards/espressif32/seeed_xiao_esp32s3.html

PLATFORM: Espressif 32 (6.9.0) > Seeed Studio XIAO ESP32S3

HARDWARE: ESP32S3 240MHz, 320KB RAM, 8MB Flash

DEBUG: Current (cmsis-dap) External (cmsis-dap, esp-bridge, esp-builtin, esp-prog, iot-bus-jtag, jlink, minimodule, olimex-arm-usb-ocd, olimex-arm-usb-ocd-h, olimex-arm-usb-tiny-h, olimex-jtag-tiny, tumpa)

PACKAGES: 

 - framework-arduinoespressif32 @ 3.20017.241212+sha.dcc1105b 

 - tool-esptoolpy @ 1.40501.0 (4.5.1) 

 - toolchain-riscv32-esp @ 8.4.0+2021r2-patch5 

 - toolchain-xtensa-esp32s3 @ 8.4.0+2021r2-patch5

LDF: Library Dependency Finder -> https://bit.ly/configure-pio-ldf

LDF Modes: Finder ~ chain, Compatibility ~ soft

Found 34 compatible libraries

Scanning dependencies...

Dependency Graph

|-- WebSockets @ 2.6.1

|-- WiFi @ 2.0.0

|-- WebServer @ 2.0.0

|-- Ethernet @ 2.0.0

|-- SPI @ 2.0.0

|-- WiFiClientSecure @ 2.0.0

Building in release mode

Compiling .pio\build\xiao-car-vga\src\camera\main.cpp.o

Compiling .pio\build\xiao-car-vga\src\prototype\main.cpp.o

Compiling .pio\build\xiao-car-vga\src\prototype\motor_pwm_idf.cpp.o

Compiling .pio\build\xiao-car-vga\src\prototype\servo_pwm_idf.cpp.o

Building .pio\build\xiao-car-vga\bootloader.bin

Generating partitions .pio\build\xiao-car-vga\partitions.bin

esptool.py v4.5.1

Creating esp32s3 image...

Merged 1 ELF section

Successfully created esp32s3 image.

Compiling .pio\build\xiao-car-vga\libeb0\WiFi\WiFi.cpp.o

Compiling .pio\build\xiao-car-vga\libeb0\WiFi\WiFiAP.cpp.o

Compiling .pio\build\xiao-car-vga\libeb0\WiFi\WiFiClient.cpp.o

Compiling .pio\build\xiao-car-vga\libeb0\WiFi\WiFiGeneric.cpp.o

Compiling .pio\build\xiao-car-vga\libeb0\WiFi\WiFiMulti.cpp.o

Compiling .pio\build\xiao-car-vga\libeb0\WiFi\WiFiSTA.cpp.o

Compiling .pio\build\xiao-car-vga\libeb0\WiFi\WiFiScan.cpp.o

Compiling .pio\build\xiao-car-vga\libeb0\WiFi\WiFiServer.cpp.o

Compiling .pio\build\xiao-car-vga\libeb0\WiFi\WiFiUdp.cpp.o

Compiling .pio\build\xiao-car-vga\libd4a\Ethernet\ETH.cpp.o

Compiling .pio\build\xiao-car-vga\lib2d7\SPI\SPI.cpp.o

Compiling .pio\build\xiao-car-vga\lib081\WiFiClientSecure\WiFiClientSecure.cpp.o

Compiling .pio\build\xiao-car-vga\lib081\WiFiClientSecure\esp_crt_bundle.c.o

Compiling .pio\build\xiao-car-vga\lib081\WiFiClientSecure\ssl_client.cpp.o

Compiling .pio\build\xiao-car-vga\lib22b\WebSockets\SocketIOclient.cpp.o

Compiling .pio\build\xiao-car-vga\lib22b\WebSockets\WebSockets.cpp.o

Compiling .pio\build\xiao-car-vga\lib22b\WebSockets\WebSocketsClient.cpp.o

Compiling .pio\build\xiao-car-vga\lib22b\WebSockets\WebSocketsServer.cpp.o

Compiling .pio\build\xiao-car-vga\lib22b\WebSockets\libb64\cdecode.c.o

Compiling .pio\build\xiao-car-vga\lib22b\WebSockets\libb64\cencode.c.o

Archiving .pio\build\xiao-car-vga\libeb0\libWiFi.a

Compiling .pio\build\xiao-car-vga\lib22b\WebSockets\libsha1\libsha1.c.o

Indexing .pio\build\xiao-car-vga\libeb0\libWiFi.a

Compiling .pio\build\xiao-car-vga\lib14a\FS\FS.cpp.o

Compiling .pio\build\xiao-car-vga\lib14a\FS\vfs_api.cpp.o

Compiling .pio\build\xiao-car-vga\lib2aa\WebServer\Parsing.cpp.o

Compiling .pio\build\xiao-car-vga\lib2aa\WebServer\WebServer.cpp.o

Archiving .pio\build\xiao-car-vga\lib2d7\libSPI.a

Indexing .pio\build\xiao-car-vga\lib2d7\libSPI.a

Archiving .pio\build\xiao-car-vga\libd4a\libEthernet.a

Compiling .pio\build\xiao-car-vga\lib2aa\WebServer\detail\mimetable.cpp.o

Indexing .pio\build\xiao-car-vga\libd4a\libEthernet.a

Compiling .pio\build\xiao-car-vga\FrameworkArduino\Esp.cpp.o

Compiling .pio\build\xiao-car-vga\FrameworkArduino\FirmwareMSC.cpp.o

Compiling .pio\build\xiao-car-vga\FrameworkArduino\FunctionalInterrupt.cpp.o

Archiving .pio\build\xiao-car-vga\lib081\libWiFiClientSecure.a

Indexing .pio\build\xiao-car-vga\lib081\libWiFiClientSecure.a

Compiling .pio\build\xiao-car-vga\FrameworkArduino\HWCDC.cpp.o

Compiling .pio\build\xiao-car-vga\FrameworkArduino\HardwareSerial.cpp.o

Compiling .pio\build\xiao-car-vga\FrameworkArduino\IPAddress.cpp.o

Compiling .pio\build\xiao-car-vga\FrameworkArduino\IPv6Address.cpp.o

Archiving .pio\build\xiao-car-vga\lib22b\libWebSockets.a

Compiling .pio\build\xiao-car-vga\FrameworkArduino\MD5Builder.cpp.o

Compiling .pio\build\xiao-car-vga\FrameworkArduino\Print.cpp.o

Indexing .pio\build\xiao-car-vga\lib22b\libWebSockets.a

Archiving .pio\build\xiao-car-vga\lib14a\libFS.a

Compiling .pio\build\xiao-car-vga\FrameworkArduino\Stream.cpp.o

Indexing .pio\build\xiao-car-vga\lib14a\libFS.a

Compiling .pio\build\xiao-car-vga\FrameworkArduino\StreamString.cpp.o

Compiling .pio\build\xiao-car-vga\FrameworkArduino\Tone.cpp.o

Compiling .pio\build\xiao-car-vga\FrameworkArduino\USB.cpp.o

Compiling .pio\build\xiao-car-vga\FrameworkArduino\USBCDC.cpp.o

Compiling .pio\build\xiao-car-vga\FrameworkArduino\USBMSC.cpp.o

Archiving .pio\build\xiao-car-vga\lib2aa\libWebServer.a

Indexing .pio\build\xiao-car-vga\lib2aa\libWebServer.a

Compiling .pio\build\xiao-car-vga\FrameworkArduino\WMath.cpp.o

Compiling .pio\build\xiao-car-vga\FrameworkArduino\WString.cpp.o

Compiling .pio\build\xiao-car-vga\FrameworkArduino\base64.cpp.o

Compiling .pio\build\xiao-car-vga\FrameworkArduino\cbuf.cpp.o

Compiling .pio\build\xiao-car-vga\FrameworkArduino\esp32-hal-adc.c.o

Compiling .pio\build\xiao-car-vga\FrameworkArduino\esp32-hal-bt.c.o

Compiling .pio\build\xiao-car-vga\FrameworkArduino\esp32-hal-cpu.c.o

Compiling .pio\build\xiao-car-vga\FrameworkArduino\esp32-hal-dac.c.o

Compiling .pio\build\xiao-car-vga\FrameworkArduino\esp32-hal-gpio.c.o

Compiling .pio\build\xiao-car-vga\FrameworkArduino\esp32-hal-i2c-slave.c.o

Compiling .pio\build\xiao-car-vga\FrameworkArduino\esp32-hal-i2c.c.o

Compiling .pio\build\xiao-car-vga\FrameworkArduino\esp32-hal-ledc.c.o

Compiling .pio\build\xiao-car-vga\FrameworkArduino\esp32-hal-matrix.c.o

Compiling .pio\build\xiao-car-vga\FrameworkArduino\esp32-hal-misc.c.o

Compiling .pio\build\xiao-car-vga\FrameworkArduino\esp32-hal-psram.c.o

Compiling .pio\build\xiao-car-vga\FrameworkArduino\esp32-hal-rgb-led.c.o

Compiling .pio\build\xiao-car-vga\FrameworkArduino\esp32-hal-rmt.c.o

Compiling .pio\build\xiao-car-vga\FrameworkArduino\esp32-hal-sigmadelta.c.o

Compiling .pio\build\xiao-car-vga\FrameworkArduino\esp32-hal-spi.c.o

Compiling .pio\build\xiao-car-vga\FrameworkArduino\esp32-hal-time.c.o

Compiling .pio\build\xiao-car-vga\FrameworkArduino\esp32-hal-timer.c.o

Compiling .pio\build\xiao-car-vga\FrameworkArduino\esp32-hal-tinyusb.c.o

Compiling .pio\build\xiao-car-vga\FrameworkArduino\esp32-hal-touch.c.o

Compiling .pio\build\xiao-car-vga\FrameworkArduino\esp32-hal-uart.c.o

Compiling .pio\build\xiao-car-vga\FrameworkArduino\firmware_msc_fat.c.o

Compiling .pio\build\xiao-car-vga\FrameworkArduino\libb64\cdecode.c.o

Compiling .pio\build\xiao-car-vga\FrameworkArduino\libb64\cencode.c.o

Compiling .pio\build\xiao-car-vga\FrameworkArduino\main.cpp.o

Compiling .pio\build\xiao-car-vga\FrameworkArduino\stdlib_noniso.c.o

Compiling .pio\build\xiao-car-vga\FrameworkArduino\wiring_pulse.c.o

Compiling .pio\build\xiao-car-vga\FrameworkArduino\wiring_shift.c.o

Archiving .pio\build\xiao-car-vga\libFrameworkArduino.a

Indexing .pio\build\xiao-car-vga\libFrameworkArduino.a

Linking .pio\build\xiao-car-vga\firmware.elf

Retrieving maximum program size .pio\build\xiao-car-vga\firmware.elf

Checking size .pio\build\xiao-car-vga\firmware.elf

Advanced Memory Usage is available via "PlatformIO Home > Project Inspect"

RAM:   [==        ]  15.5% (used 50824 bytes from 327680 bytes)

Flash: [==        ]  24.7% (used 827029 bytes from 3342336 bytes)

Building .pio\build\xiao-car-vga\firmware.bin

esptool.py v4.5.1

Creating esp32s3 image...

Merged 2 ELF sections

Successfully created esp32s3 image.

========================= [SUCCESS] Took 17.44 seconds =========================

Environment      Status    Duration

---------------  --------  ------------

esp32-bench      SUCCESS   00:00:21.958

esp32-bench-sta  SUCCESS   00:00:16.146

xiao-car-qvga    SUCCESS   00:00:22.734

xiao-car-vga     SUCCESS   00:00:17.445

========================= 4 succeeded in 00:01:18.283 =========================

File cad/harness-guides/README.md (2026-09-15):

# Направляющие проводов и обслуживание — 0.1

15 сентября 2026. Продолжение [держателя XIAO](../xiao-mount/README.md).
Две направляющие добавлены непосредственно в печатные детали: силовая — в
левый край поддона, серво — в боковое крыло верхнего прижима XIAO.

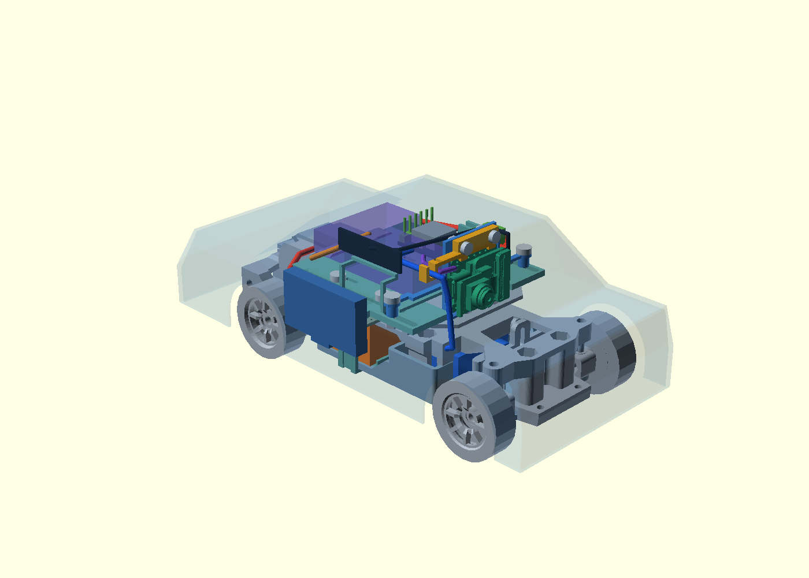
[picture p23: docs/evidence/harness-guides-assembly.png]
Общая сборка с направляющими


[Крупный вид](../../docs/evidence/harness-guides-close.png) ·
[Редактируемые детали](../harness-guides.scad) ·
[Редактируемая сборка](../harness-guides-assembly.scad) ·
[Отчёт](../../docs/evidence/harness-guides-v01.json).

## Удержание и изготовление

Это открытые седловидные направляющие, **не защёлки**. Провод укладывается сверху
и дополнительно удерживается съёмной стяжкой либо шнуром. В силовой направляющей
есть проход 2,8×1,3 мм под седлом; на крыле прижима — отверстие 1,3×2,8 мм.
Радиус ложа 1,25 мм рассчитан как резерв относительно нынешних коридоров проводов
радиусами 1,0 и 0,9 мм. Он не устанавливает сечение жил или диаметр реального жгута.
Конкретные стяжки, их замки, затяжка и допустимое сдавливание изоляции ещё не выбраны.

Направляющие объединены со своими основаниями в замкнутые связные тела.
Дополнительный клей или саморезы для их крепления не предусмотрены.
Гибкость консольного крыла, прочность печати и удержание при ударе не проверены.
Остальные провода пока не имеют новых фиксаторов; это не законченный жгут машины.

Для примерки подготовлены:

- [Поддон с силовой направляющей](tray_print.stl), около 53,25×48×8,5 мм.
- [Прижим с направляющей серво](cap_print.stl), около 32,75×8,2×3,5 мм.

Они заменяют прежние поддон с выемкой и прижим в этой итерации. Опора XIAO,
крепёж, схема электрических соединений и размеры остальных плат не менялись.
Экспорты расположены на Z≈0; ориентацию, мосты/поддержки и профиль K1C ещё нужно
проверить в слайсере. G-code и фактическая печать не выполнялись.

## Повторная проверка обслуживания

Проверяется **начальная компоновка: платы 0 мм, камера +3 мм**. Используются новая
опора, прижим, крепёж XIAO и переложенные трассы из предыдущей итерации, а не старая
опора 0.5. Сервисный USB остаётся направленным по +X; его резерв проверен отдельно.

| Проверка | Объём проверки | Результат для учтённой геометрии |
| --- | --- | --- |
| Новые направляющие | Детали электроники, 103 ограничивающих объёма STEP, трассы, крепёж, резерв сервисного USB | Непредусмотренных пересечений нет; объединение с собственной печатной основой намеренное |
| Посадка под кузовом | Новые поддон и прижим против полости условного кузова | Выхода за полость нет |
| Снятие кузова с крышкой зарядного порта | +2 мм Z, затем +1 мм X, затем подъём до +65 мм Z; 76 положений | Пересечений нет |
| Снятие левого упора батареи | 6 мм наружу, 25 положений | Пересечений нет |
| Выход батареи влево | Весь объём прямого хода макета на 50 мм; кузов/ремешок/левый упор сняты, правый оставлен | Пересечений нет |
| Снятие нового прижима | +1,1 мм Z, затем +8 мм Y; 28 положений | Пересечений нет при снятых винтах и отведённом проводе серво |

Перед снятием прижима требуется освободить его стяжку и **вынуть провод серво из
направляющей**, затем отвести его. Свободная форма провода и достаточность его
гибкости/запаса длины не моделировались. Для обычной замены батареи прижим снимать
не требуется. Снятие кузова моделируется с отключённым внешним USB-кабелем.

Контрольные неправильные операции действительно обнаруживаются: выход батареи
с левым упором даёт 123,000 мм³ пересечения; прямой подъём кузова на 7 мм —
14,821 мм³ пересечения с зарядным USB. Числа характеризуют коллизии, не силу удержания.

Проверка кузова/упора/прижима выполнена в отдельных положениях; только для коробки
батареи проверен непрерывный прямой ход. Не учтены пальцы, реальные разъёмы и хвост
аккумулятора, форма стяжек, магниты, некоторые детали исходной подвески/передачи,
нагрузки, другой кузов и другие положения регулировок. Батарея и часть электроники
остаются размерными резервами; камера — справочная STEP 2023, не измеренная OV3660.
Физическая посадка, зарядка, радиосвязь и готовность машины к заезду не подтверждены.

Воспроизведение:

```powershell
uv run --with-requirements tools/cad-candidate-requirements.txt python tools/build_harness_guides.py
```

Отчёт содержит SHA256 входов. Трассы восстанавливаются из точек/радиусов исходных
отчётов, чтобы не использовать незамкнутый STL силового провода как твёрдое тело.
Происхождение заимствованных моделей и их лицензии сохраняются по
[NOTICE компоновки](../packaging-v05/NOTICE.md) и [источнику zcar](../reference/NOTICE.md).

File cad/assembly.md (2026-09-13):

# Общая компоновка 0.1

13 сентября 2026. **Есть общая 3D-сцена, но проект машинки ещё не закончен.** Это проверка распределения места и первая конструкция площадки электроники. Сборки/печати на железе не было.

Для дальнейшей работы предложена [компоновка под кузов 0.2](body-study.md): условная оболочка и более низкое размещение электроники. Вариант 0.1 ниже сохранён для сравнения; его высота 62 мм не является принятым габаритом машины. Исправлена ориентация: перед по +Y, камера перенесена к рулевой оси.

Открыть [assembly-viewer.html](assembly-viewer.html) в Chrome: работает локально без сервера, интернета и внешних библиотек. Можно вращать модель, скрывать группы, смотреть сверху/сбоку и разнести детали по высоте. Для редактирования — [assembly.scad](assembly.scad), OpenSCAD, просмотр F5. Исходная сборка zcar незамкнутая; F6/экспорт всей машины единым печатным телом не является поддерживаемым результатом.

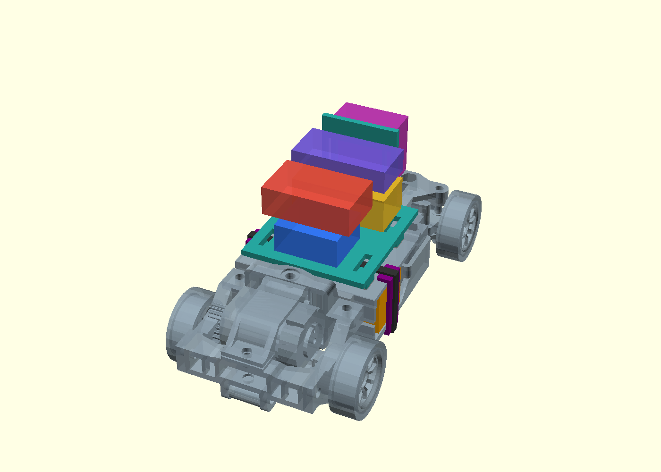
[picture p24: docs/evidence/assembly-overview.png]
Общая компоновка с габаритными резервами электроники


## Что изображено

- Серая механика — исходная сборка zcar: рама, колёса, рулевой узел, мотор и передача. Она перенесена в общую систему координат без изменения формы. Посадка новых F130/SG90 и предложенная передача 9:43 здесь ещё не реализованы. Включён исходный [SketchUp-файл автора](reference/zcar.skp); это не наш законченный проект.
- Оранжевая батарея — макет 49×18×15 мм, с нашими опорой, упорами и резервом ремешка 0.2.
- Зелёная площадка — новая деталь 43×46 мм с четырьмя опорами, пазами под будущие ремешки и вертикальной стойкой за камерой. Четыре площадки 6×6 мм опираются через резерв клеевого слоя 0,5 мм на полку zcar. Основание находится на Z=24…26 мм, стойка до Z=55 мм.
- Остальные цветные блоки — **габаритные бюджеты**, не точные 3D-модели уже выбранных плат. Между нижними платами и площадкой оставлен 1 мм под изоляцию/крепление; крепление верхнего уровня ещё не создано.

| Блок | Размер X×Y×Z, мм | Нижний угол, мм | Что означает |
| --- | --- | --- | --- |
| Контроллер | 22×18×10 | 13,75; 43; 27 | Резерв компактной платы; имеющаяся WROOM-32U devboard не измерена и не объявлена помещающейся сюда |
| Преобразователь 5 В | 33×16×12 | 8,25; 67; 27 | Площадь по Waveshare, высота 12 мм — наш резерв под вариант с разъёмами, не измеренная высота |
| Камера | 23×12×21 | 13,25; 87; 32 | Резерв компактного модуля класса XIAO в вертикальном положении. Не подтверждает посадку Waveshare CAM-WAV-01, кабелей и угол обзора |
| Драйвер | 30×18×10 | 9,75; 43; 40 | Бюджет будущей силовой платы, TA6586 с обвязкой ещё не разведён |
| Зарядка | 33×16×8 | 8,25; 67; 42 | Бюджет узла 2S, не модель выбранного зарядника/USB-C |

Размеры условных блоков — ограничения для дальнейшего подбора/разводки. Если конкретный модуль больше, менять компоновку, а не уменьшать его макет. Разнесение в просмотрщике не является рассчитанной последовательностью монтажа.

## Проверка и выявленные ограничения

[Числовой отчёт](../docs/evidence/assembly-layout.json) фиксирует исходные SHA256, размеры, попарные пересечения и результаты проверки:

- Добавленные объёмы не пересекают закрытые модели рамы/полки, батарейный узел и друг друга. Проверен прямой боковой ход батареи на 50 мм после освобождения её упоров.
- Для незамкнутых частей исходной сборки применены консервативные ограничивающие объёмы. Широкая проверка площадки задевает плоские фрагменты модели, но уточнение по каждому ограничивающему объёму даёт нулевое пересечение. Отверстия исходной сборки не залечивались ради положительного результата.
- Каждая ножка имеет 36 мм² геометрического контакта с полкой через зарезервированный клеевой слой. Это не испытание клея/жёсткости. При намеренном опускании площадки на 5 мм возникает коллизия — положительная контрольная проверка.
- Габариты сцены около **65×123,625×62 мм**, включая исходные колёса и стойку. Совместимость с низким кузовом Mini-Z не подтверждена. Следующая итерация снижает высоту электроники с учётом кузова; увеличивать кузов только для укрытия прежней стопки плат не принято как решение.

Пока не покрыты: полный ход руля/подвески, кабели, антенна, реальные разъёмы, снятие эластичного ремешка под площадкой, вибрация/удары, магниты и кузов. Свободный ход батарейного бруска не доказывает удобство обслуживания. Верхние драйвер/зарядник пока показаны без стоек и крепления, камера — без проверенного крепежа. Эта сцена не закрывает MOUNT-01/MECH-01/SWAP-01.

[electronics-carrier.stl](electronics-carrier.stl) — экспорт одного замкнутого тела, не готовое задание принтеру. Ориентацию, поддержки для нависающего основания/стойки, материал и допуски ещё выбрать. Его не следует считать проверенной заменой печатных деталей zcar.

## Воспроизведение

После подготовки исходного клона и батарейной компоновки по [README](README.md), из корня репозитория:

```powershell
uv run --with-requirements tools/cad-requirements.txt python tools/build_cad_assembly.py
```

Скрипт экспортирует детали OpenSCAD, проверяет геометрию, обновляет автономный HTML, PNG, STL площадки и отчёт. [Шаблон просмотрщика](../tools/cad_viewer_template.html) — отдельный редактируемый исходник; HTML в cad генерируется из него. После изменения SCAD нужно пересоздать HTML/отчёт, иначе он показывает прежнюю геометрию. Проверены просмотр в Chrome, переключение вида, скрытие площадки и разнесение на 25 мм; WebGL вернул код ошибки 0 после действий. Это проверка интерфейса, не механики.

Происхождение исходной механики, неизменённый редактируемый источник и GPL-3.0 сохранены в [reference](reference/NOTICE.md). Файлы сборки доступны непосредственно из репозитория, без зависимостей просмотра на игнорируемый build.

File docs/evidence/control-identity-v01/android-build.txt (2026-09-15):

> Task :buildSrc:compileKotlin UP-TO-DATE

> Task :buildSrc:compileJava NO-SOURCE

> Task :buildSrc:compileGroovy NO-SOURCE

> Task :buildSrc:pluginDescriptors UP-TO-DATE

> Task :buildSrc:processResources NO-SOURCE

> Task :buildSrc:classes UP-TO-DATE

> Task :buildSrc:inspectClassesForKotlinIC UP-TO-DATE

> Task :buildSrc:jar UP-TO-DATE

> Task :buildSrc:assemble UP-TO-DATE

> Task :buildSrc:compileTestKotlin NO-SOURCE

> Task :buildSrc:pluginUnderTestMetadata UP-TO-DATE

> Task :buildSrc:compileTestJava NO-SOURCE

> Task :buildSrc:compileTestGroovy NO-SOURCE

> Task :buildSrc:processTestResources NO-SOURCE

> Task :buildSrc:testClasses UP-TO-DATE

> Task :buildSrc:test NO-SOURCE

> Task :buildSrc:validatePlugins UP-TO-DATE

> Task :buildSrc:check UP-TO-DATE

> Task :buildSrc:build UP-TO-DATE

> Configure project :app

ComposeOptions.kotlinCompilerVersion is deprecated. Compose now uses the kotlin compiler defined in your buildscript.

> Task :app:preBuild UP-TO-DATE

> Task :app:preDebugBuild UP-TO-DATE

> Task :app:compileDebugAidl NO-SOURCE

> Task :app:compileDebugRenderscript NO-SOURCE

> Task :app:generateDebugBuildConfig UP-TO-DATE

> Task :app:checkDebugAarMetadata UP-TO-DATE

> Task :app:generateDebugResValues UP-TO-DATE

> Task :app:mapDebugSourceSetPaths UP-TO-DATE

> Task :app:generateDebugResources UP-TO-DATE

> Task :app:mergeDebugResources UP-TO-DATE

> Task :app:createDebugCompatibleScreenManifests UP-TO-DATE

> Task :app:extractDeepLinksDebug UP-TO-DATE

> Task :app:processDebugMainManifest UP-TO-DATE

> Task :app:processDebugManifest UP-TO-DATE

> Task :app:processDebugManifestForPackage UP-TO-DATE

> Task :app:processDebugResources UP-TO-DATE

> Task :app:javaPreCompileDebug UP-TO-DATE

> Task :app:preDebugUnitTestBuild UP-TO-DATE

> Task :app:javaPreCompileDebugUnitTest UP-TO-DATE

> Task :app:processDebugJavaRes NO-SOURCE

> Task :app:processDebugUnitTestJavaRes NO-SOURCE

> Task :app:mergeDebugNativeDebugMetadata NO-SOURCE

> Task :app:mergeDebugShaders UP-TO-DATE

> Task :app:compileDebugShaders NO-SOURCE

> Task :app:generateDebugAssets UP-TO-DATE

> Task :app:mergeDebugAssets UP-TO-DATE

> Task :app:compressDebugAssets UP-TO-DATE

> Task :app:checkDebugDuplicateClasses UP-TO-DATE

> Task :app:desugarDebugFileDependencies UP-TO-DATE

> Task :app:mergeExtDexDebug UP-TO-DATE

> Task :app:mergeLibDexDebug UP-TO-DATE

> Task :app:mergeDebugJniLibFolders UP-TO-DATE

> Task :app:mergeDebugNativeLibs NO-SOURCE

> Task :app:stripDebugDebugSymbols NO-SOURCE

> Task :app:validateSigningDebug UP-TO-DATE

> Task :app:writeDebugAppMetadata UP-TO-DATE

> Task :app:writeDebugSigningConfigVersions UP-TO-DATE

> Task :app:preDebugAndroidTestBuild SKIPPED

> Task :app:compileDebugAndroidTestAidl NO-SOURCE

> Task :app:processDebugAndroidTestManifest UP-TO-DATE

> Task :app:compileDebugAndroidTestRenderscript NO-SOURCE

> Task :app:generateDebugAndroidTestBuildConfig UP-TO-DATE

> Task :app:checkDebugAndroidTestAarMetadata UP-TO-DATE

> Task :app:generateDebugAndroidTestResValues UP-TO-DATE

> Task :app:mapDebugAndroidTestSourceSetPaths UP-TO-DATE

> Task :app:generateDebugAndroidTestResources UP-TO-DATE

> Task :app:mergeDebugAndroidTestResources UP-TO-DATE

> Task :app:processDebugAndroidTestResources UP-TO-DATE

> Task :app:javaPreCompileDebugAndroidTest UP-TO-DATE

> Task :app:mergeDebugAndroidTestShaders UP-TO-DATE

> Task :app:compileDebugAndroidTestShaders NO-SOURCE

> Task :app:generateDebugAndroidTestAssets UP-TO-DATE

> Task :app:mergeDebugAndroidTestAssets UP-TO-DATE

> Task :app:compressDebugAndroidTestAssets UP-TO-DATE

> Task :app:processDebugAndroidTestJavaRes NO-SOURCE

> Task :app:mergeDebugAndroidTestJniLibFolders UP-TO-DATE

> Task :app:mergeDebugAndroidTestNativeLibs NO-SOURCE

> Task :app:checkDebugAndroidTestDuplicateClasses UP-TO-DATE

> Task :app:desugarDebugAndroidTestFileDependencies UP-TO-DATE

> Task :app:mergeExtDexDebugAndroidTest UP-TO-DATE

> Task :app:mergeLibDexDebugAndroidTest UP-TO-DATE

> Task :app:validateSigningDebugAndroidTest UP-TO-DATE

> Task :app:writeDebugAndroidTestSigningConfigVersions UP-TO-DATE

> Task :app:compileDebugKotlin

w: file:///C:/Users/Evgeny/orca/RaceRemote/app/src/main/java/vea/raceremote/control/CarControlScreen.kt:78:36 'getter for allNetworks: Array<(out) Network!>' is deprecated. Deprecated in Java

> Task :app:compileDebugJavaWithJavac UP-TO-DATE

> Task :app:mergeDebugJavaResource UP-TO-DATE

> Task :app:bundleDebugClassesToRuntimeJar

> Task :app:bundleDebugClassesToCompileJar

> Task :app:dexBuilderDebug

> Task :app:compileDebugUnitTestKotlin

> Task :app:mergeProjectDexDebug

> Task :app:compileDebugUnitTestJavaWithJavac NO-SOURCE

> Task :app:compileDebugAndroidTestKotlin

> Task :app:testDebugUnitTest

> Task :app:compileDebugAndroidTestJavaWithJavac UP-TO-DATE

> Task :app:mergeDebugAndroidTestJavaResource UP-TO-DATE

> Task :app:dexBuilderDebugAndroidTest

> Task :app:packageDebug

> Task :app:createDebugApkListingFileRedirect UP-TO-DATE

> Task :app:assembleDebug

> Task :app:mergeProjectDexDebugAndroidTest

> Task :app:packageDebugAndroidTest

> Task :app:createDebugAndroidTestApkListingFileRedirect UP-TO-DATE

> Task :app:assembleDebugAndroidTest

Deprecated Gradle features were used in this build, making it incompatible with Gradle 8.0.

You can use '--warning-mode all' to show the individual deprecation warnings and determine if they come from your own scripts or plugins.

See https://docs.gradle.org/7.5/userguide/command_line_interface.html#sec:command_line_warnings

BUILD SUCCESSFUL in 9s

66 actionable tasks: 12 executed, 54 up-to-date

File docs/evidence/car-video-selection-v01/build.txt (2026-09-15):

> Task :buildSrc:compileKotlin UP-TO-DATE
> Task :buildSrc:compileJava NO-SOURCE
> Task :buildSrc:compileGroovy NO-SOURCE
> Task :buildSrc:pluginDescriptors UP-TO-DATE
> Task :buildSrc:processResources NO-SOURCE
> Task :buildSrc:classes UP-TO-DATE
> Task :buildSrc:inspectClassesForKotlinIC UP-TO-DATE
> Task :buildSrc:jar UP-TO-DATE
> Task :buildSrc:assemble UP-TO-DATE
> Task :buildSrc:compileTestKotlin NO-SOURCE
> Task :buildSrc:pluginUnderTestMetadata UP-TO-DATE
> Task :buildSrc:compileTestJava NO-SOURCE
> Task :buildSrc:compileTestGroovy NO-SOURCE
> Task :buildSrc:processTestResources NO-SOURCE
> Task :buildSrc:testClasses UP-TO-DATE
> Task :buildSrc:test NO-SOURCE
> Task :buildSrc:validatePlugins UP-TO-DATE
> Task :buildSrc:check UP-TO-DATE
> Task :buildSrc:build UP-TO-DATE

> Configure project :app
ComposeOptions.kotlinCompilerVersion is deprecated. Compose now uses the kotlin compiler defined in your buildscript.

> Task :app:preBuild UP-TO-DATE
> Task :app:preDebugBuild UP-TO-DATE
> Task :app:compileDebugAidl NO-SOURCE
> Task :app:compileDebugRenderscript NO-SOURCE
> Task :app:generateDebugBuildConfig UP-TO-DATE
> Task :app:checkDebugAarMetadata UP-TO-DATE
> Task :app:generateDebugResValues UP-TO-DATE
> Task :app:mapDebugSourceSetPaths UP-TO-DATE
> Task :app:generateDebugResources UP-TO-DATE
> Task :app:mergeDebugResources UP-TO-DATE
> Task :app:createDebugCompatibleScreenManifests UP-TO-DATE
> Task :app:extractDeepLinksDebug UP-TO-DATE
> Task :app:processDebugMainManifest UP-TO-DATE
> Task :app:processDebugManifest UP-TO-DATE
> Task :app:processDebugManifestForPackage UP-TO-DATE
> Task :app:processDebugResources UP-TO-DATE
> Task :app:compileDebugKotlin UP-TO-DATE
> Task :app:javaPreCompileDebug UP-TO-DATE
> Task :app:compileDebugJavaWithJavac UP-TO-DATE
> Task :app:bundleDebugClassesToRuntimeJar UP-TO-DATE
> Task :app:bundleDebugClassesToCompileJar UP-TO-DATE
> Task :app:compileDebugUnitTestKotlin UP-TO-DATE
> Task :app:preDebugUnitTestBuild UP-TO-DATE
> Task :app:javaPreCompileDebugUnitTest UP-TO-DATE
> Task :app:compileDebugUnitTestJavaWithJavac NO-SOURCE
> Task :app:processDebugJavaRes NO-SOURCE
> Task :app:processDebugUnitTestJavaRes NO-SOURCE
> Task :app:testDebugUnitTest UP-TO-DATE
> Task :app:mergeDebugNativeDebugMetadata NO-SOURCE
> Task :app:mergeDebugShaders UP-TO-DATE
> Task :app:compileDebugShaders NO-SOURCE
> Task :app:generateDebugAssets UP-TO-DATE
> Task :app:mergeDebugAssets UP-TO-DATE
> Task :app:compressDebugAssets UP-TO-DATE
> Task :app:mergeDebugJavaResource UP-TO-DATE
> Task :app:checkDebugDuplicateClasses UP-TO-DATE
> Task :app:desugarDebugFileDependencies UP-TO-DATE
> Task :app:mergeExtDexDebug UP-TO-DATE
> Task :app:mergeLibDexDebug UP-TO-DATE
> Task :app:dexBuilderDebug UP-TO-DATE
> Task :app:mergeProjectDexDebug UP-TO-DATE
> Task :app:mergeDebugJniLibFolders UP-TO-DATE
> Task :app:mergeDebugNativeLibs NO-SOURCE
> Task :app:stripDebugDebugSymbols NO-SOURCE
> Task :app:validateSigningDebug UP-TO-DATE
> Task :app:writeDebugAppMetadata UP-TO-DATE
> Task :app:writeDebugSigningConfigVersions UP-TO-DATE
> Task :app:packageDebug UP-TO-DATE
> Task :app:createDebugApkListingFileRedirect UP-TO-DATE
> Task :app:assembleDebug UP-TO-DATE
> Task :app:preDebugAndroidTestBuild SKIPPED
> Task :app:compileDebugAndroidTestAidl NO-SOURCE
> Task :app:processDebugAndroidTestManifest UP-TO-DATE
> Task :app:compileDebugAndroidTestRenderscript NO-SOURCE
> Task :app:generateDebugAndroidTestBuildConfig UP-TO-DATE
> Task :app:checkDebugAndroidTestAarMetadata UP-TO-DATE
> Task :app:generateDebugAndroidTestResValues UP-TO-DATE
> Task :app:mapDebugAndroidTestSourceSetPaths UP-TO-DATE
> Task :app:generateDebugAndroidTestResources UP-TO-DATE
> Task :app:mergeDebugAndroidTestResources UP-TO-DATE
> Task :app:processDebugAndroidTestResources UP-TO-DATE
> Task :app:javaPreCompileDebugAndroidTest UP-TO-DATE
> Task :app:mergeDebugAndroidTestShaders UP-TO-DATE
> Task :app:compileDebugAndroidTestShaders NO-SOURCE
> Task :app:generateDebugAndroidTestAssets UP-TO-DATE
> Task :app:mergeDebugAndroidTestAssets UP-TO-DATE
> Task :app:compressDebugAndroidTestAssets UP-TO-DATE
> Task :app:processDebugAndroidTestJavaRes NO-SOURCE
> Task :app:mergeDebugAndroidTestJniLibFolders UP-TO-DATE
> Task :app:mergeDebugAndroidTestNativeLibs NO-SOURCE
> Task :app:checkDebugAndroidTestDuplicateClasses UP-TO-DATE
> Task :app:desugarDebugAndroidTestFileDependencies UP-TO-DATE
> Task :app:mergeExtDexDebugAndroidTest UP-TO-DATE
> Task :app:mergeLibDexDebugAndroidTest UP-TO-DATE
> Task :app:validateSigningDebugAndroidTest UP-TO-DATE
> Task :app:writeDebugAndroidTestSigningConfigVersions UP-TO-DATE
> Task :app:compileDebugAndroidTestKotlin
> Task :app:compileDebugAndroidTestJavaWithJavac UP-TO-DATE
> Task :app:mergeDebugAndroidTestJavaResource UP-TO-DATE
> Task :app:dexBuilderDebugAndroidTest
> Task :app:mergeProjectDexDebugAndroidTest
> Task :app:packageDebugAndroidTest
> Task :app:createDebugAndroidTestApkListingFileRedirect UP-TO-DATE
> Task :app:assembleDebugAndroidTest

Deprecated Gradle features were used in this build, making it incompatible with Gradle 8.0.

You can use '--warning-mode all' to show the individual deprecation warnings and determine if they come from your own scripts or plugins.

See https://docs.gradle.org/7.5/userguide/command_line_interface.html#sec:command_line_warnings

BUILD SUCCESSFUL in 2s
66 actionable tasks: 4 executed, 62 up-to-date

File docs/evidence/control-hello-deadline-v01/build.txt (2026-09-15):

> Task :buildSrc:compileKotlin UP-TO-DATE
> Task :buildSrc:compileJava NO-SOURCE
> Task :buildSrc:compileGroovy NO-SOURCE
> Task :buildSrc:pluginDescriptors UP-TO-DATE
> Task :buildSrc:processResources NO-SOURCE
> Task :buildSrc:classes UP-TO-DATE
> Task :buildSrc:inspectClassesForKotlinIC UP-TO-DATE
> Task :buildSrc:jar UP-TO-DATE
> Task :buildSrc:assemble UP-TO-DATE
> Task :buildSrc:compileTestKotlin NO-SOURCE
> Task :buildSrc:pluginUnderTestMetadata UP-TO-DATE
> Task :buildSrc:compileTestJava NO-SOURCE
> Task :buildSrc:compileTestGroovy NO-SOURCE
> Task :buildSrc:processTestResources NO-SOURCE
> Task :buildSrc:testClasses UP-TO-DATE
> Task :buildSrc:test NO-SOURCE
> Task :buildSrc:validatePlugins UP-TO-DATE
> Task :buildSrc:check UP-TO-DATE
> Task :buildSrc:build UP-TO-DATE

> Configure project :app
ComposeOptions.kotlinCompilerVersion is deprecated. Compose now uses the kotlin compiler defined in your buildscript.

> Task :app:preBuild UP-TO-DATE
> Task :app:preDebugBuild UP-TO-DATE
> Task :app:compileDebugAidl NO-SOURCE
> Task :app:compileDebugRenderscript NO-SOURCE
> Task :app:generateDebugBuildConfig UP-TO-DATE
> Task :app:checkDebugAarMetadata UP-TO-DATE
> Task :app:generateDebugResValues UP-TO-DATE
> Task :app:mapDebugSourceSetPaths UP-TO-DATE
> Task :app:generateDebugResources UP-TO-DATE
> Task :app:mergeDebugResources UP-TO-DATE
> Task :app:createDebugCompatibleScreenManifests UP-TO-DATE
> Task :app:extractDeepLinksDebug UP-TO-DATE
> Task :app:processDebugMainManifest UP-TO-DATE
> Task :app:processDebugManifest UP-TO-DATE
> Task :app:processDebugManifestForPackage UP-TO-DATE
> Task :app:processDebugResources UP-TO-DATE
> Task :app:javaPreCompileDebug UP-TO-DATE
> Task :app:preDebugUnitTestBuild UP-TO-DATE
> Task :app:javaPreCompileDebugUnitTest UP-TO-DATE
> Task :app:processDebugJavaRes NO-SOURCE
> Task :app:processDebugUnitTestJavaRes NO-SOURCE
> Task :app:mergeDebugNativeDebugMetadata NO-SOURCE
> Task :app:mergeDebugShaders UP-TO-DATE
> Task :app:compileDebugShaders NO-SOURCE
> Task :app:generateDebugAssets UP-TO-DATE
> Task :app:mergeDebugAssets UP-TO-DATE
> Task :app:compressDebugAssets UP-TO-DATE
> Task :app:checkDebugDuplicateClasses UP-TO-DATE
> Task :app:desugarDebugFileDependencies UP-TO-DATE
> Task :app:mergeExtDexDebug UP-TO-DATE
> Task :app:mergeLibDexDebug UP-TO-DATE
> Task :app:mergeDebugJniLibFolders UP-TO-DATE
> Task :app:mergeDebugNativeLibs NO-SOURCE
> Task :app:stripDebugDebugSymbols NO-SOURCE
> Task :app:validateSigningDebug UP-TO-DATE
> Task :app:writeDebugAppMetadata UP-TO-DATE
> Task :app:writeDebugSigningConfigVersions UP-TO-DATE
> Task :app:preDebugAndroidTestBuild SKIPPED
> Task :app:compileDebugAndroidTestAidl NO-SOURCE
> Task :app:processDebugAndroidTestManifest UP-TO-DATE
> Task :app:compileDebugAndroidTestRenderscript NO-SOURCE
> Task :app:generateDebugAndroidTestBuildConfig UP-TO-DATE
> Task :app:checkDebugAndroidTestAarMetadata UP-TO-DATE
> Task :app:generateDebugAndroidTestResValues UP-TO-DATE
> Task :app:mapDebugAndroidTestSourceSetPaths UP-TO-DATE
> Task :app:generateDebugAndroidTestResources UP-TO-DATE
> Task :app:mergeDebugAndroidTestResources UP-TO-DATE
> Task :app:processDebugAndroidTestResources UP-TO-DATE
> Task :app:javaPreCompileDebugAndroidTest UP-TO-DATE
> Task :app:mergeDebugAndroidTestShaders UP-TO-DATE
> Task :app:compileDebugAndroidTestShaders NO-SOURCE
> Task :app:generateDebugAndroidTestAssets UP-TO-DATE
> Task :app:mergeDebugAndroidTestAssets UP-TO-DATE
> Task :app:compressDebugAndroidTestAssets UP-TO-DATE
> Task :app:processDebugAndroidTestJavaRes NO-SOURCE
> Task :app:mergeDebugAndroidTestJniLibFolders UP-TO-DATE
> Task :app:mergeDebugAndroidTestNativeLibs NO-SOURCE
> Task :app:checkDebugAndroidTestDuplicateClasses UP-TO-DATE
> Task :app:desugarDebugAndroidTestFileDependencies UP-TO-DATE
> Task :app:mergeExtDexDebugAndroidTest UP-TO-DATE
> Task :app:mergeLibDexDebugAndroidTest UP-TO-DATE
> Task :app:validateSigningDebugAndroidTest UP-TO-DATE
> Task :app:writeDebugAndroidTestSigningConfigVersions UP-TO-DATE
> Task :app:compileDebugKotlin
> Task :app:compileDebugJavaWithJavac UP-TO-DATE
> Task :app:mergeDebugJavaResource UP-TO-DATE
> Task :app:bundleDebugClassesToCompileJar
> Task :app:bundleDebugClassesToRuntimeJar
> Task :app:dexBuilderDebug
> Task :app:compileDebugUnitTestKotlin
> Task :app:compileDebugUnitTestJavaWithJavac NO-SOURCE
> Task :app:compileDebugAndroidTestKotlin
> Task :app:mergeProjectDexDebug
> Task :app:testDebugUnitTest
> Task :app:compileDebugAndroidTestJavaWithJavac UP-TO-DATE
> Task :app:mergeDebugAndroidTestJavaResource UP-TO-DATE
> Task :app:dexBuilderDebugAndroidTest UP-TO-DATE
> Task :app:mergeProjectDexDebugAndroidTest UP-TO-DATE
> Task :app:packageDebugAndroidTest UP-TO-DATE
> Task :app:createDebugAndroidTestApkListingFileRedirect UP-TO-DATE
> Task :app:assembleDebugAndroidTest UP-TO-DATE
> Task :app:packageDebug
> Task :app:createDebugApkListingFileRedirect UP-TO-DATE
> Task :app:assembleDebug

Deprecated Gradle features were used in this build, making it incompatible with Gradle 8.0.

You can use '--warning-mode all' to show the individual deprecation warnings and determine if they come from your own scripts or plugins.

See https://docs.gradle.org/7.5/userguide/command_line_interface.html#sec:command_line_warnings

BUILD SUCCESSFUL in 9s
66 actionable tasks: 9 executed, 57 up-to-date

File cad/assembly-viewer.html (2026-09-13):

# RaceRemote 3D-компоновка 0.1

Габаритная проработка, не готовая машинка. Цветные блоки электроники — резерв места. Их крепления, провода, кузов и ход подвески ещё не проверены.

Силовые платы: 0 мм Камера: 0 мм

Плюс — вперёд. Проверены отдельные положения макетов через 1 мм. Провода, допуски, реальный кузов и ход подвески не проверены.

Разнести по высоте: 0 мм Общий видСверхуСбоку

Перетаскивание — вращение; колесо — масштаб. Разнесение деталей служит только для просмотра.

Редактировать в OpenSCAD · Что уже проверено

Серая механика: alexyu132/zcar, 4b714e6, GPL-3.0. Источник и лицензия. Это исходный привод, не подтверждённая посадка новых мотора/серво или передача 9:43.

Перед: +Y, рулевая ось Y = 111,125 · Сзади: ведущая ось Y = 21,125 · мм

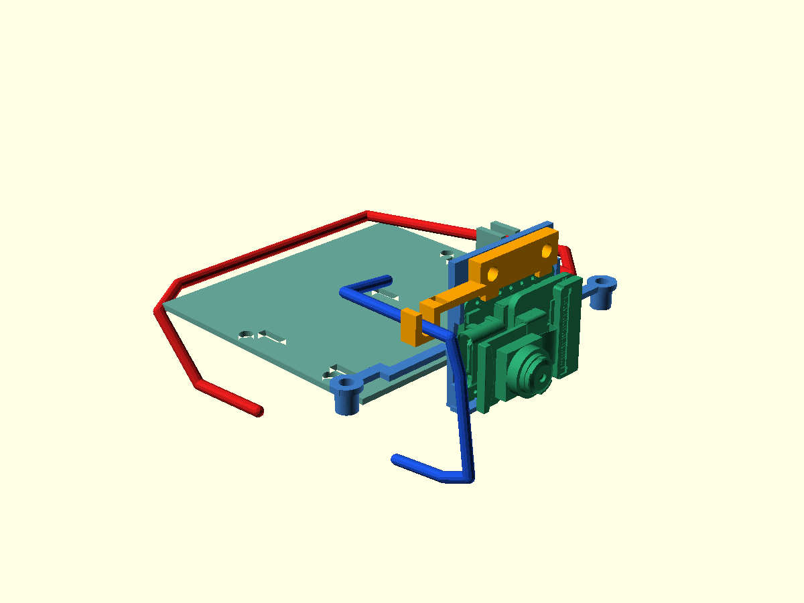
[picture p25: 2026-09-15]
docs/evidence/harness-guides-close.png

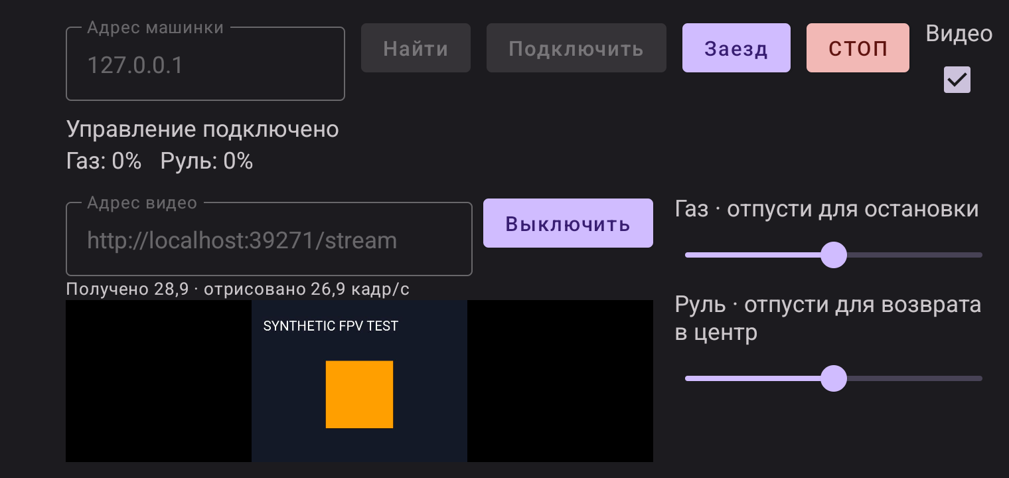
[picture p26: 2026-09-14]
docs/evidence/driving-mode-2026-09-14/driving-setup.png

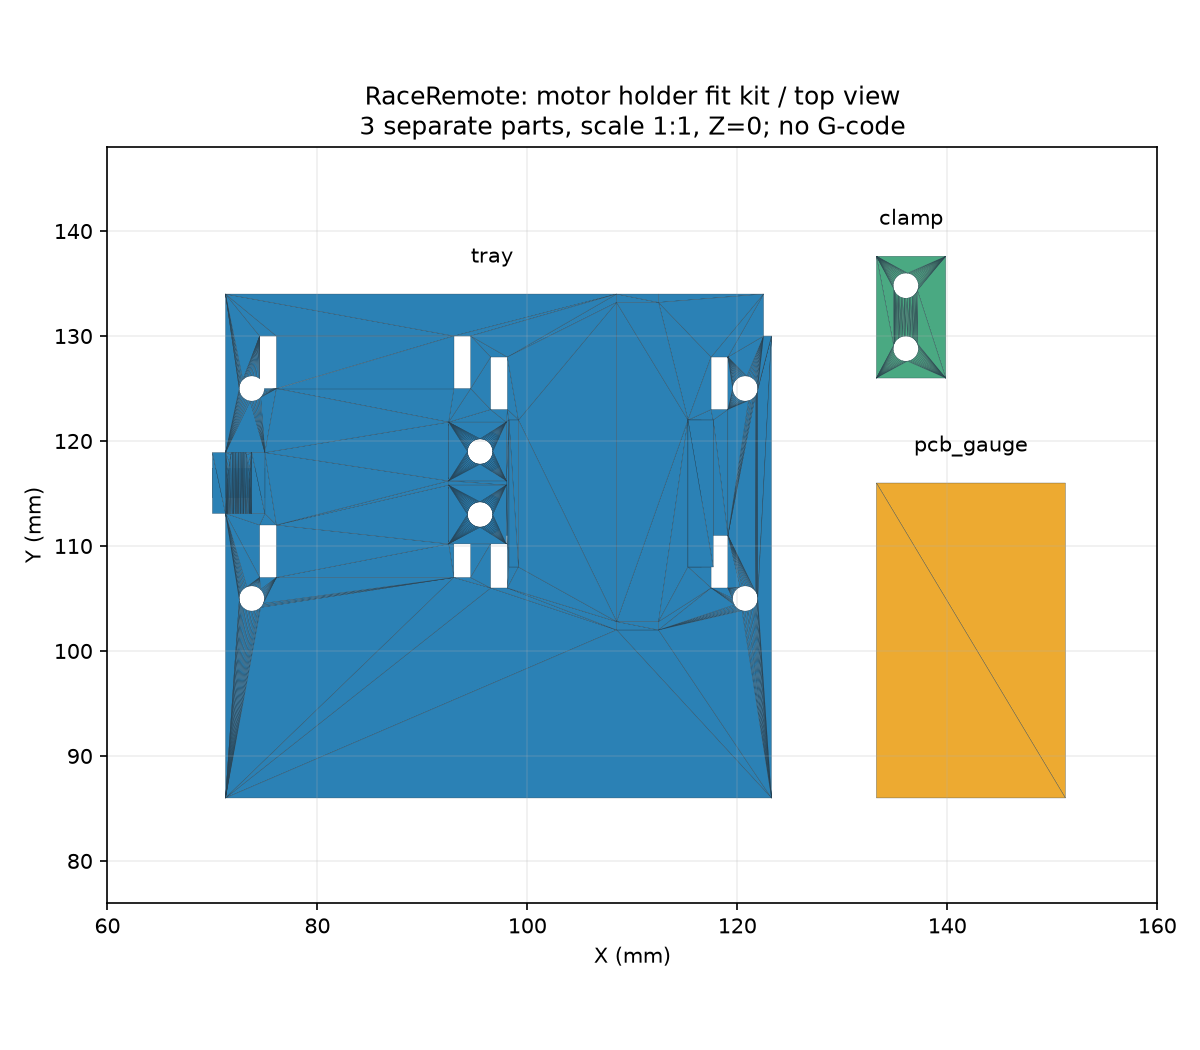
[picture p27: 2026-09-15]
cad/motor-carrier-mount/print-kit.png

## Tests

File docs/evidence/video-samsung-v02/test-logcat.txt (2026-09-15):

09-15 18:14:35.701 25743 25809 I TestRunner: run started: 4 tests
09-15 18:14:35.702 25743 25809 I TestRunner: started: unavailableVideoDoesNotStopControlAndBackgroundStopsBoth(vea.raceremote.VideoControlIsolationTest)
09-15 18:14:40.203 25743 25809 I TestRunner: finished: unavailableVideoDoesNotStopControlAndBackgroundStopsBoth(vea.raceremote.VideoControlIsolationTest)
09-15 18:14:40.208 25743 25809 I TestRunner: started: repeatedCaptureTimesOutVideoWhileControlContinuesAndReconnectStartsFresh(vea.raceremote.VideoControlIsolationTest)
09-15 18:14:42.202 25743 25809 D RaceRemoteVideoTest: Video center pixel=ff0000fe
09-15 18:14:44.417 25743 25809 D RaceRemoteVideoTest: Video center pixel=ff000000
09-15 18:14:45.631 25743 25809 D RaceRemoteVideoTest: Video center pixel=ff0000fe
09-15 18:14:45.966 25743 25809 I TestRunner: finished: repeatedCaptureTimesOutVideoWhileControlContinuesAndReconnectStartsFresh(vea.raceremote.VideoControlIsolationTest)
09-15 18:14:45.970 25743 25809 I TestRunner: started: backgroundDuringDragDoesNotResumeControl(vea.raceremote.DrivingModeTest)
09-15 18:14:47.935 25743 25809 I TestRunner: finished: backgroundDuringDragDoesNotResumeControl(vea.raceremote.DrivingModeTest)
09-15 18:14:47.938 25743 25809 I TestRunner: started: twoThumbsCancelAndVideoSurviveModeChanges(vea.raceremote.DrivingModeTest)
09-15 18:14:52.548 25743 25809 I TestRunner: finished: twoThumbsCancelAndVideoSurviveModeChanges(vea.raceremote.DrivingModeTest)
09-15 18:14:52.551 25743 25809 I TestRunner: run finished: 4 tests, 0 failed, 0 ignored

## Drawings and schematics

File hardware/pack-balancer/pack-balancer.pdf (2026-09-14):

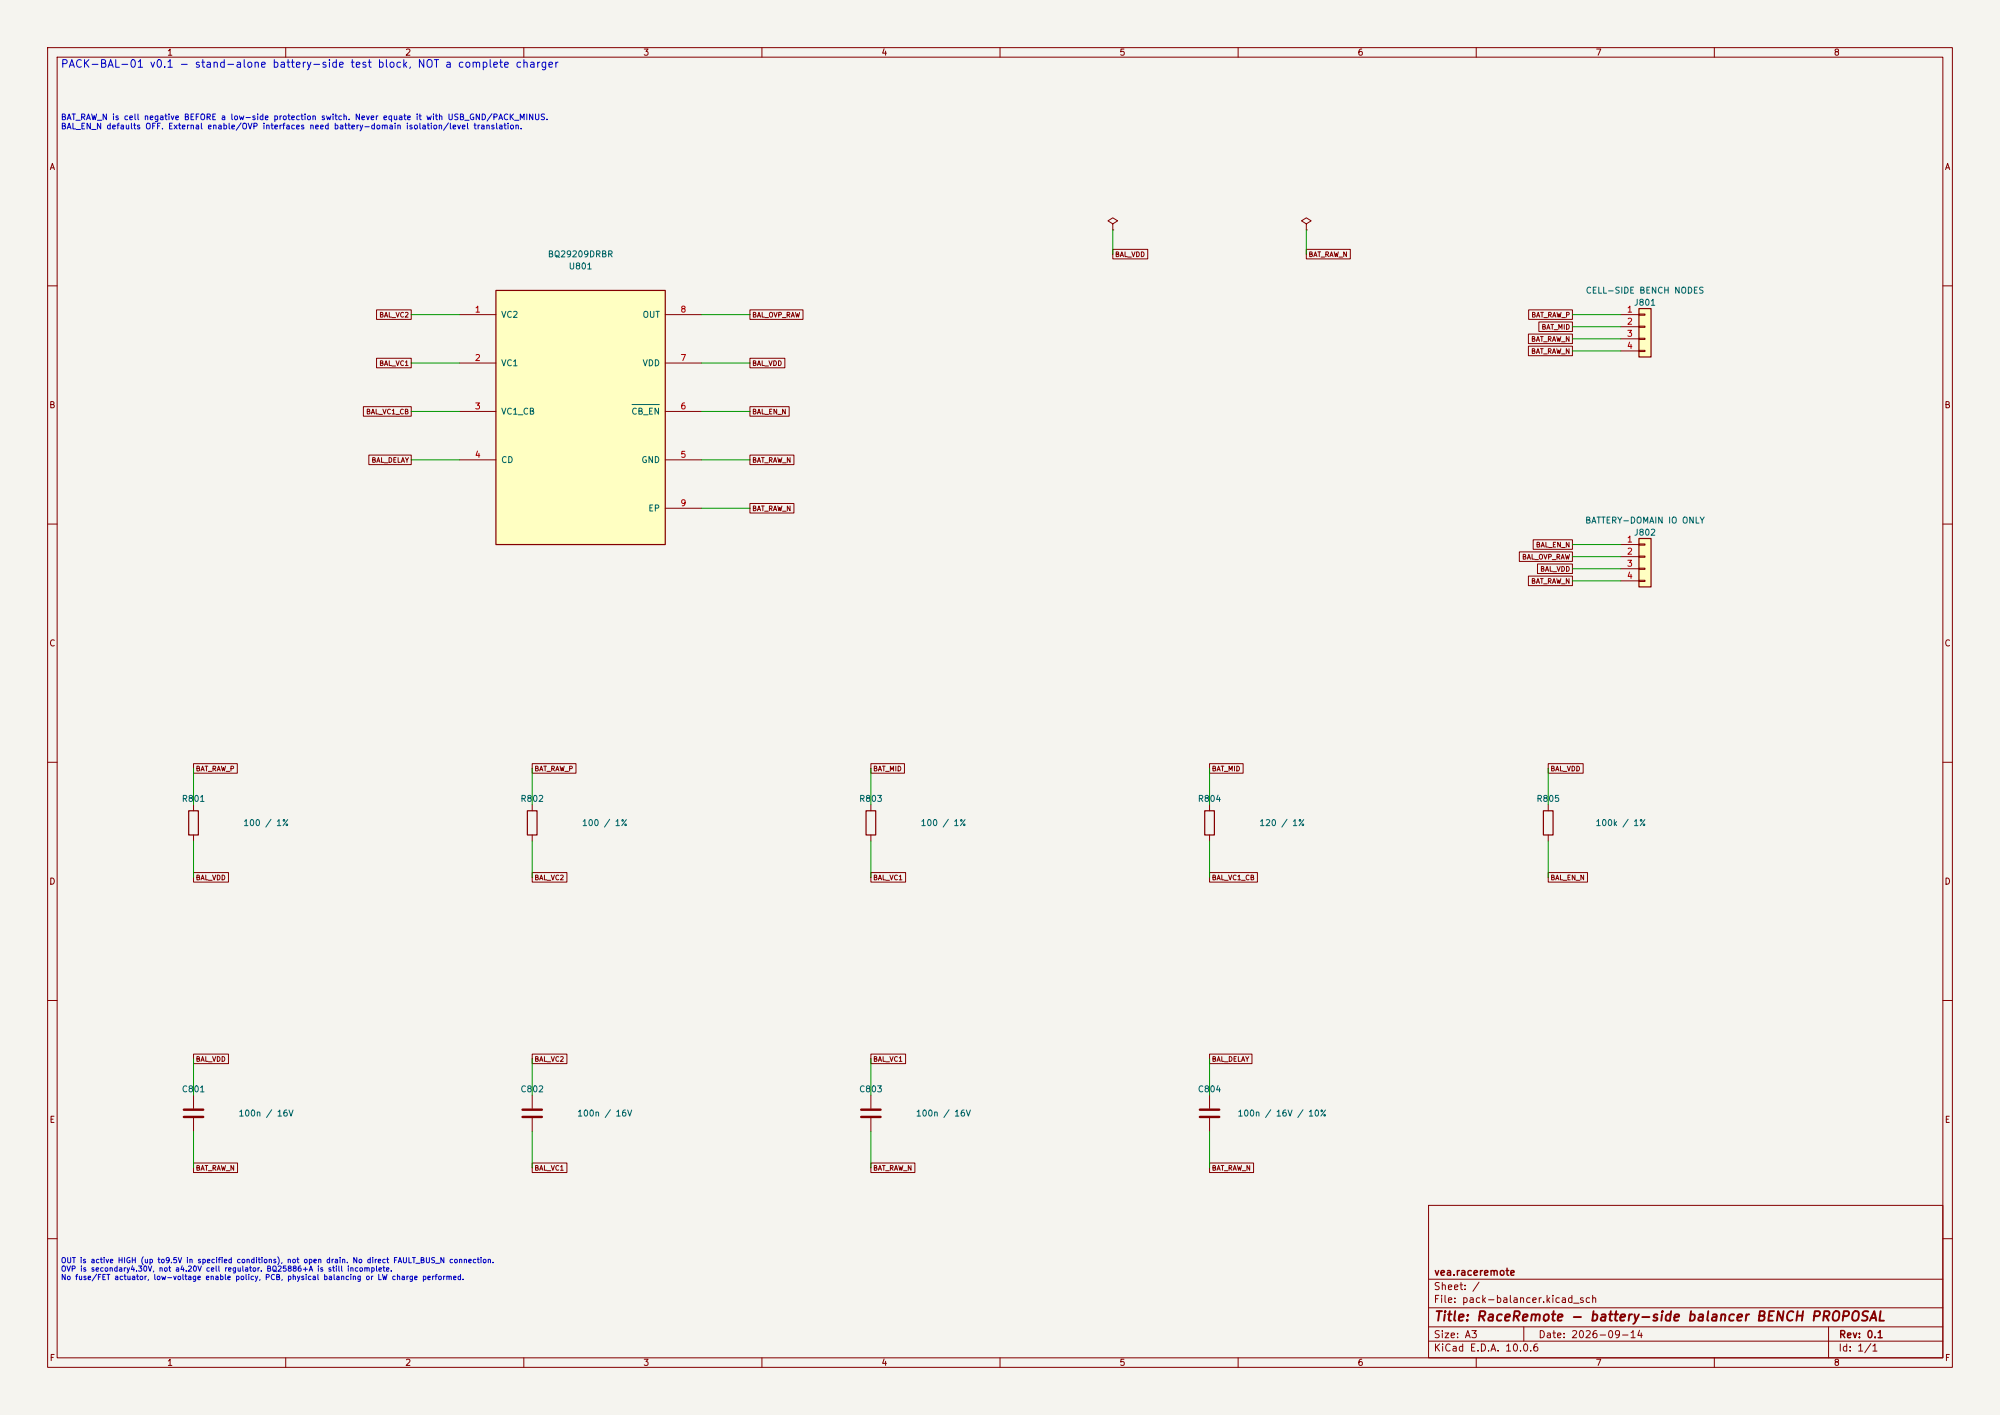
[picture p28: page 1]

BAT_RAW_N is cell negative BEFORE a low-side protection switch. Never equate it with USB_GND/PACK_MINUS. BAL_EN_N defaults OFF. External enable/OVP interfaces need battery-domain isolation/level translation. PACK-BAL-01 v0.1 - stand-alone battery-side test block, NOT a complete charger

J801 CELL-SIDE BENCH NODES

J802 BATTERY-DOMAIN IO ONLY R805

BAL_DELAY OUT is active HIGH (up to9.5V in specified conditions), not open drain. No direct FAULT_BUS_N connection. OVP is secondary4.30V, not a4.20V cell regulator. BQ25886+A is still incomplete. No fuse/FET actuator, low-voltage enable policy, PCB, physical balancing or LW charge performed.

vea.raceremote
Sheet: /
File: pack-balancer.kicad_sch
Title: RaceRemote - battery-side balancer BENCH PROPOSAL

Size: A3 | Rev: 0.1 | F Date: 2026-09-14
KiCad E.D.A. 10.0.6 | Id: 1/1

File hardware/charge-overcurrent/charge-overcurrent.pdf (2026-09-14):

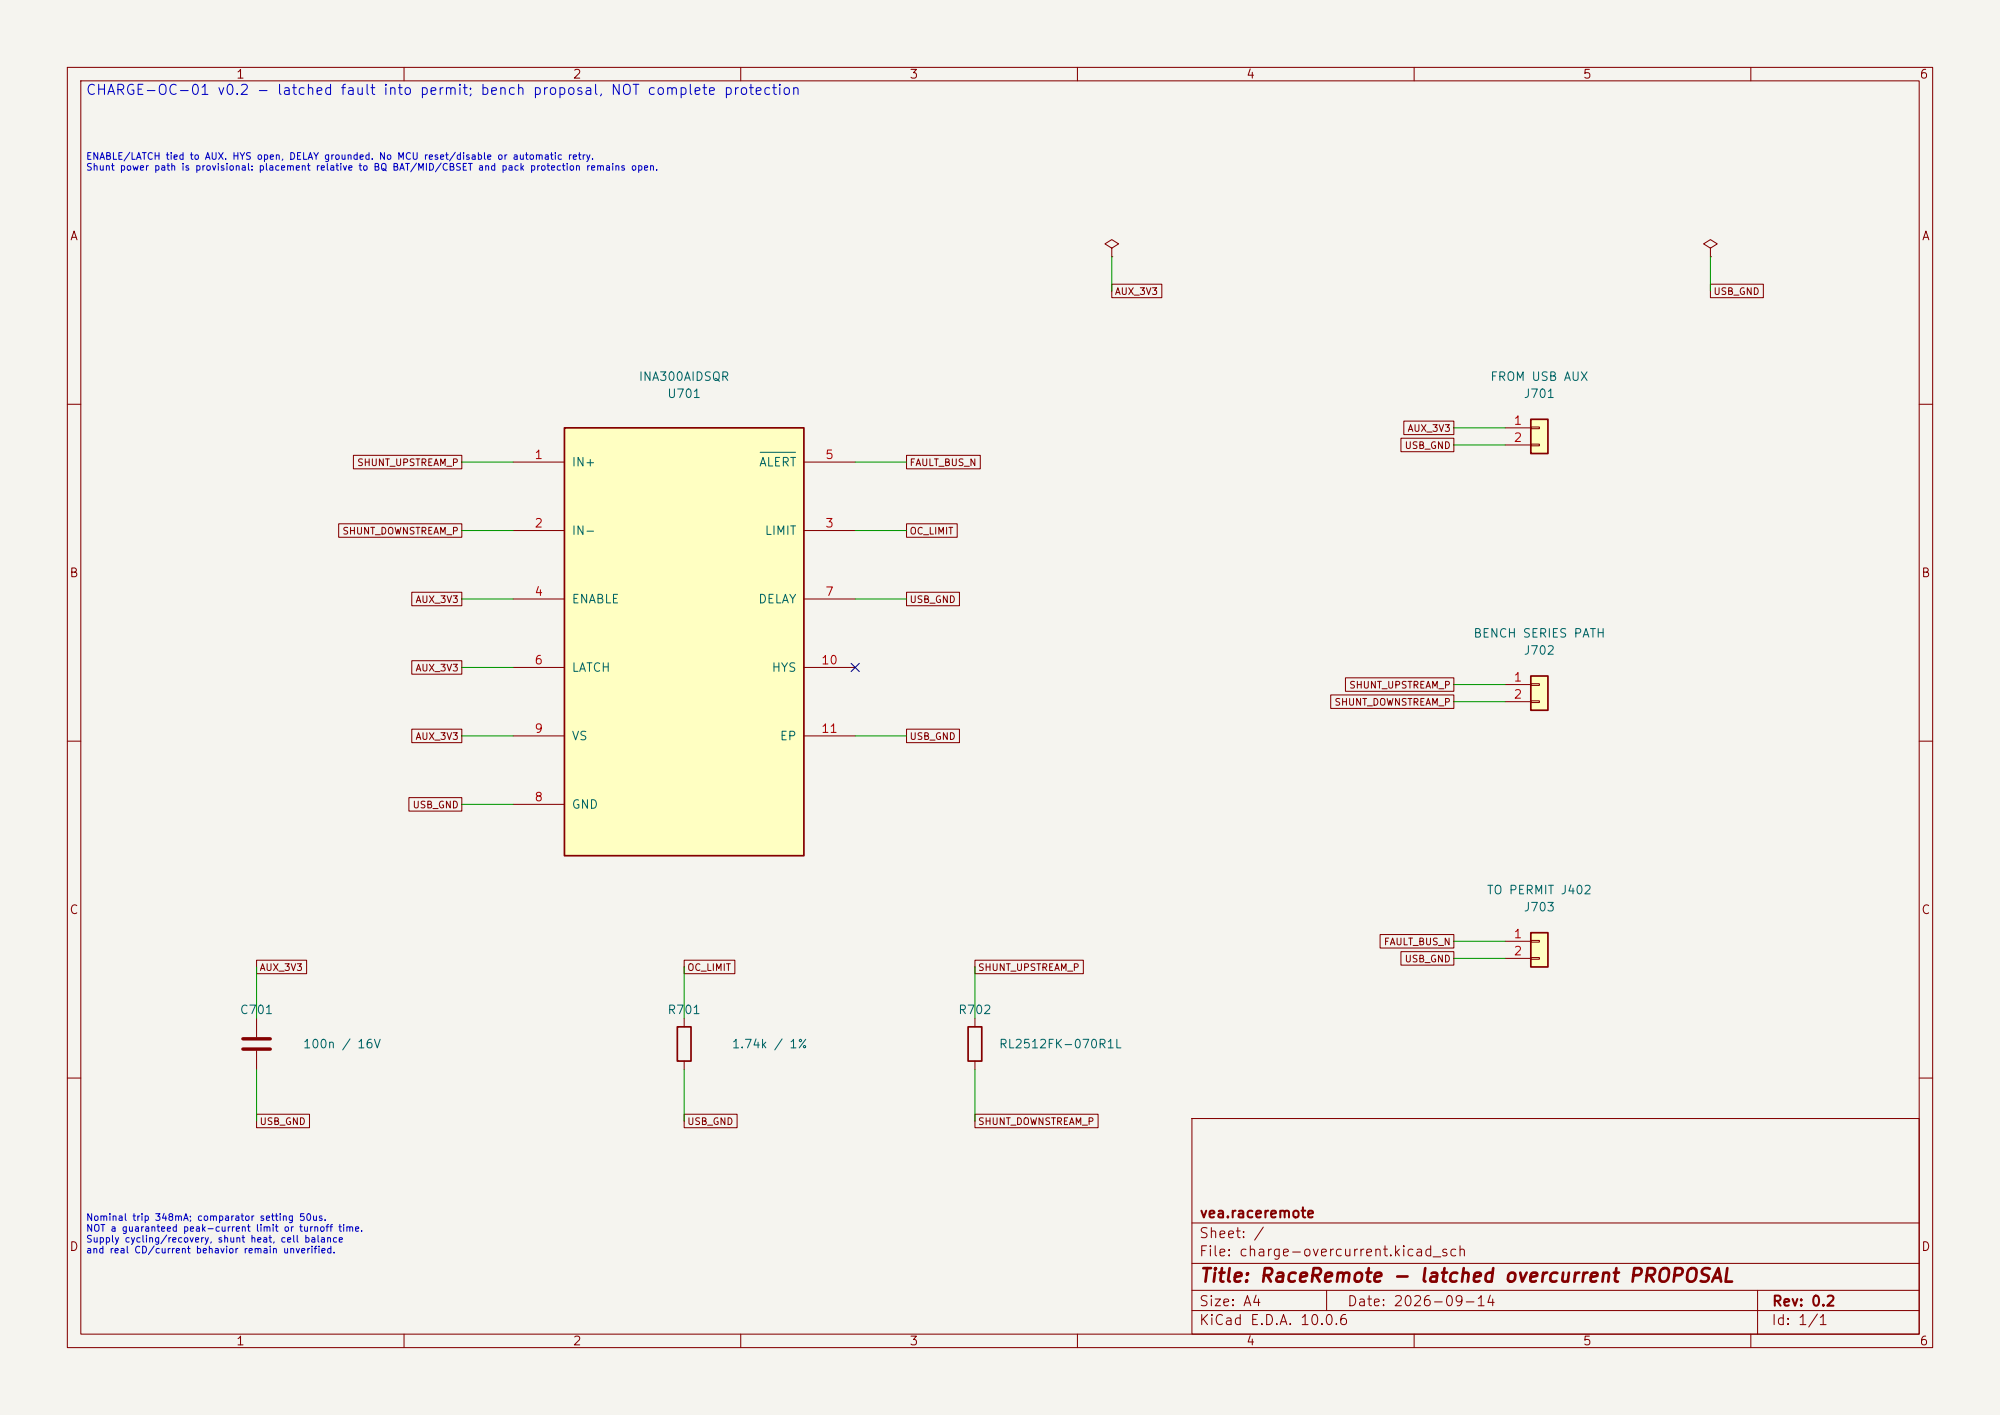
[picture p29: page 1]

ENABLE/LATCH tied to AUX. HYS open, DELAY grounded. No MCU reset/disable or automatic retry. Shunt power path is provisional: placement relative to BQ BAT/MID/CBSET and pack protection remains open.

vea.raceremote
Sheet: /
File: charge-overcurrent.kicad_sch
Title: RaceRemote - latched overcurrent PROPOSAL

Nominal trip 348mA; comparator setting 50us. NOT a guaranteed peak-current limit or turnoff time. Supply cycling/recovery, shunt heat, cell balance and real CD/current behavior remain unverified.

Size: A4 | Rev: 0.2
KiCad E.D.A. 10.0.6 | Id: 1/1

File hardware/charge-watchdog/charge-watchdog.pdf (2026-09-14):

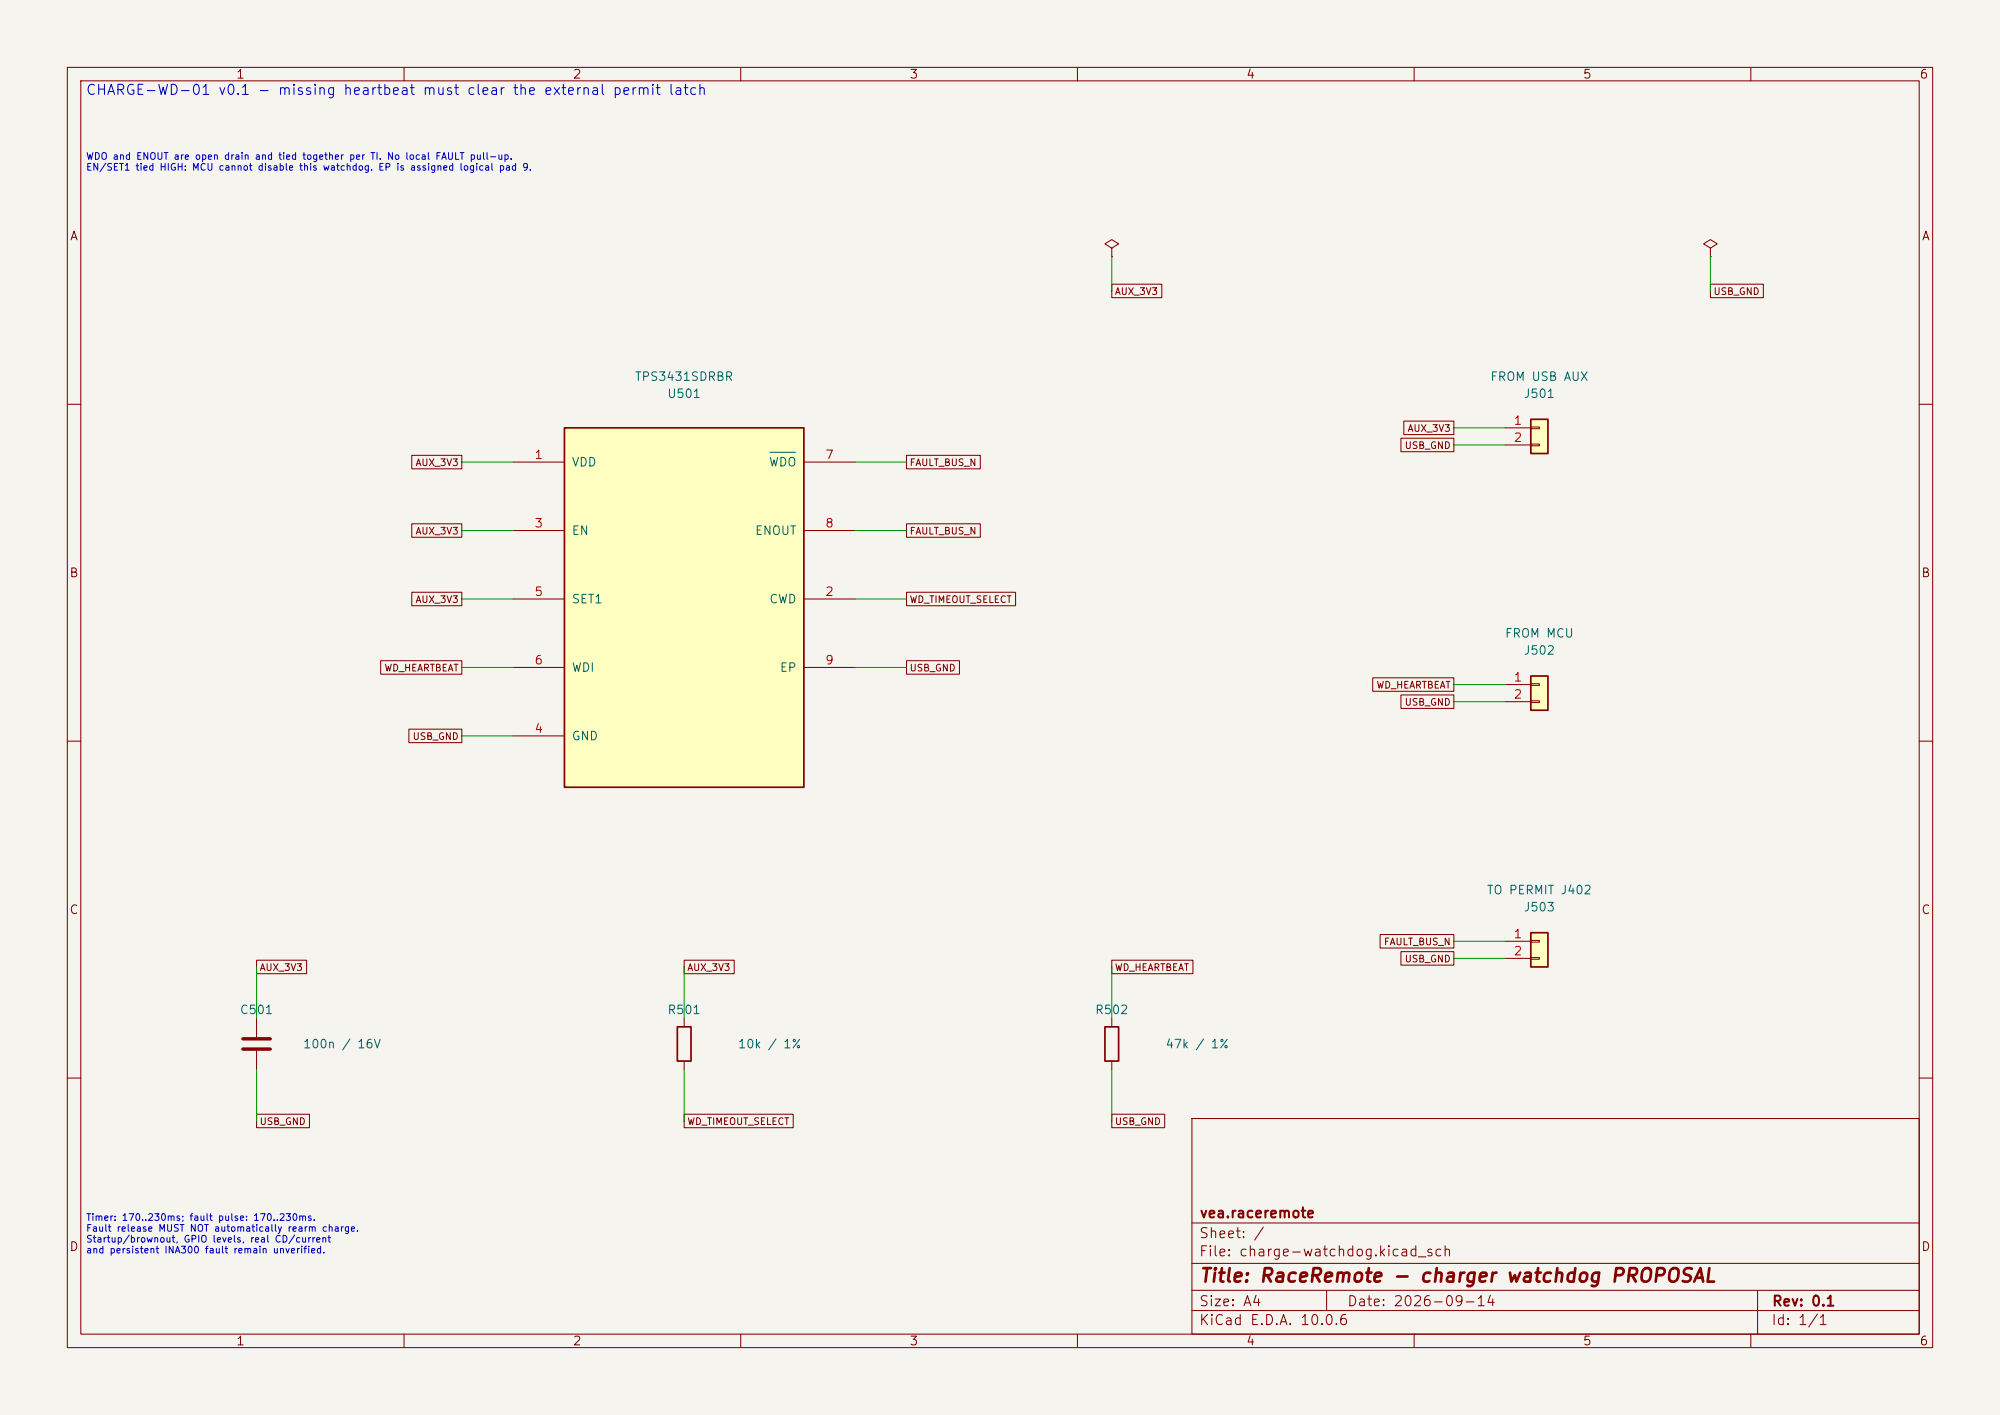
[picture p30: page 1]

CHARGE-WD-01 v0.1 - missing heartbeat must clear the external permit latch

WDO and ENOUT are open drain and tied together per TI. No local FAULT pull-up. EN/SET1 tied HIGH: MCU cannot disable this watchdog. EP is assigned logical pad 9.

vea.raceremote
Sheet: /
File: charge-watchdog.kicad_sch
Title: RaceRemote - charger watchdog PROPOSAL

Timer: 170..230ms; fault pulse: 170..230ms. Fault release MUST NOT automatically rearm charge. Startup/brownout, GPIO levels, real CD/current and persistent INA300 fault remain unverified.

Size: A4 | Rev: 0.1
KiCad E.D.A. 10.0.6 | Id: 1/1

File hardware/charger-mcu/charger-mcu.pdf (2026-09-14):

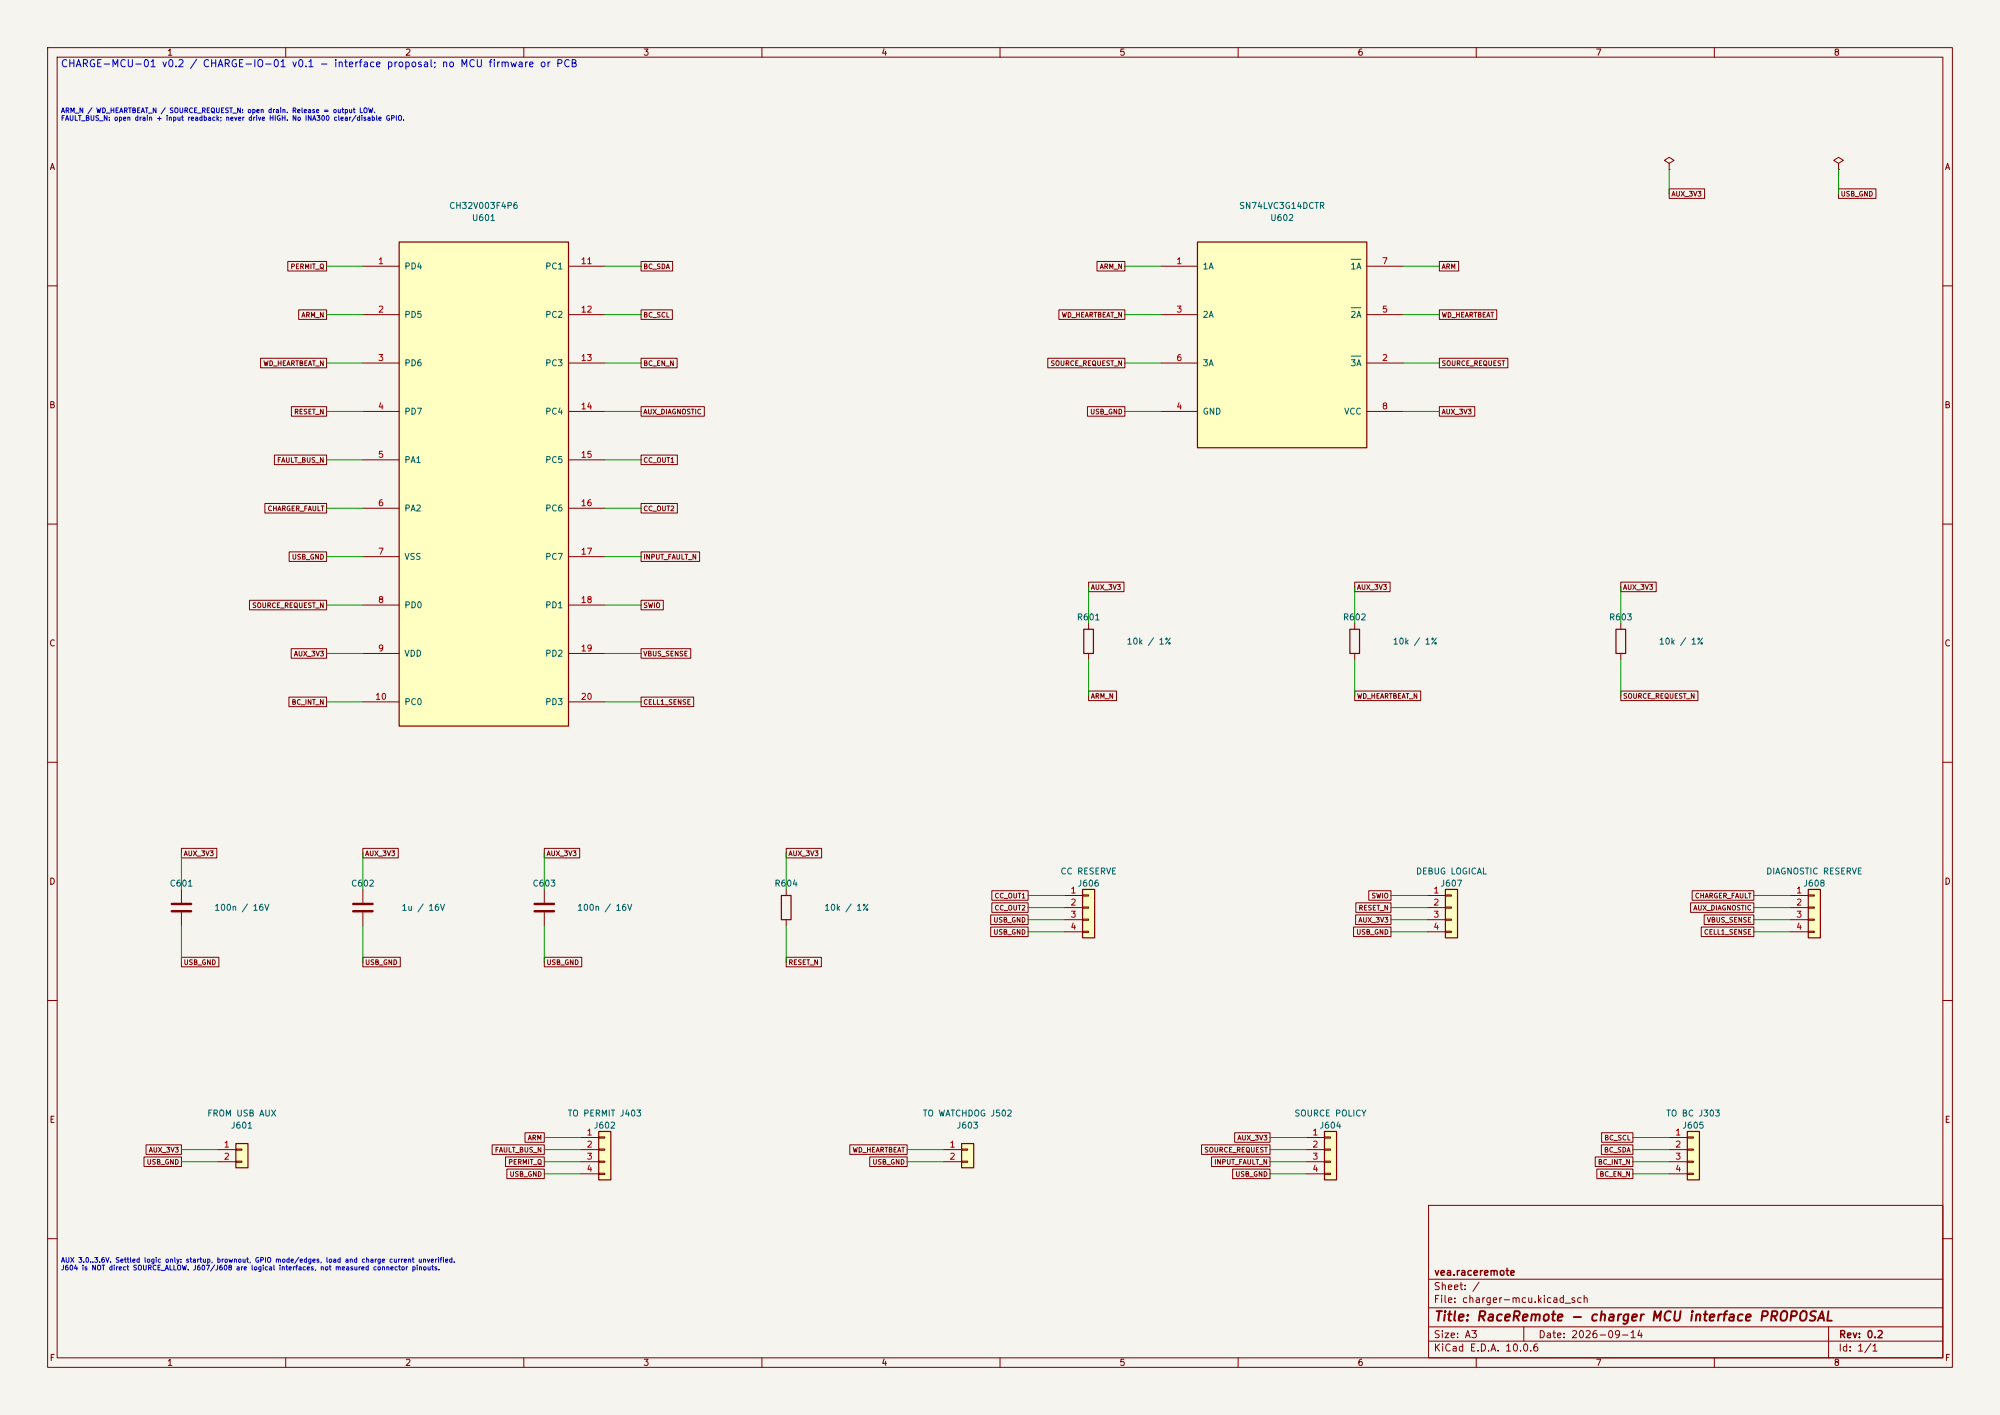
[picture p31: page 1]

CHARGE-MCU-01 v0.2 / CHARGE-IO-01 v0.1 - interface proposal; no MCU firmware or PCB

ARM_N / WD_HEARTBEAT_N / SOURCE_REQUEST_N: open drain. Release = output LOW. FAULT_BUS_N: open drain + input readback; never drive HIGH. No INA300 clear/disable GPIO.

AUX 3.0..3.6V. Settled logic only: startup, brownout, GPIO mode/edges, load and charge current unverified. J604 is NOT direct SOURCE_ALLOW. J607/J608 are logical interfaces, not measured connector pinouts.

vea.raceremote
Sheet: /
File: charger-mcu.kicad_sch
Title: RaceRemote - charger MCU interface PROPOSAL

Size: A3 | Rev: 0.2 | F Date: 2026-09-14
KiCad E.D.A. 10.0.6 | Id: 1/1

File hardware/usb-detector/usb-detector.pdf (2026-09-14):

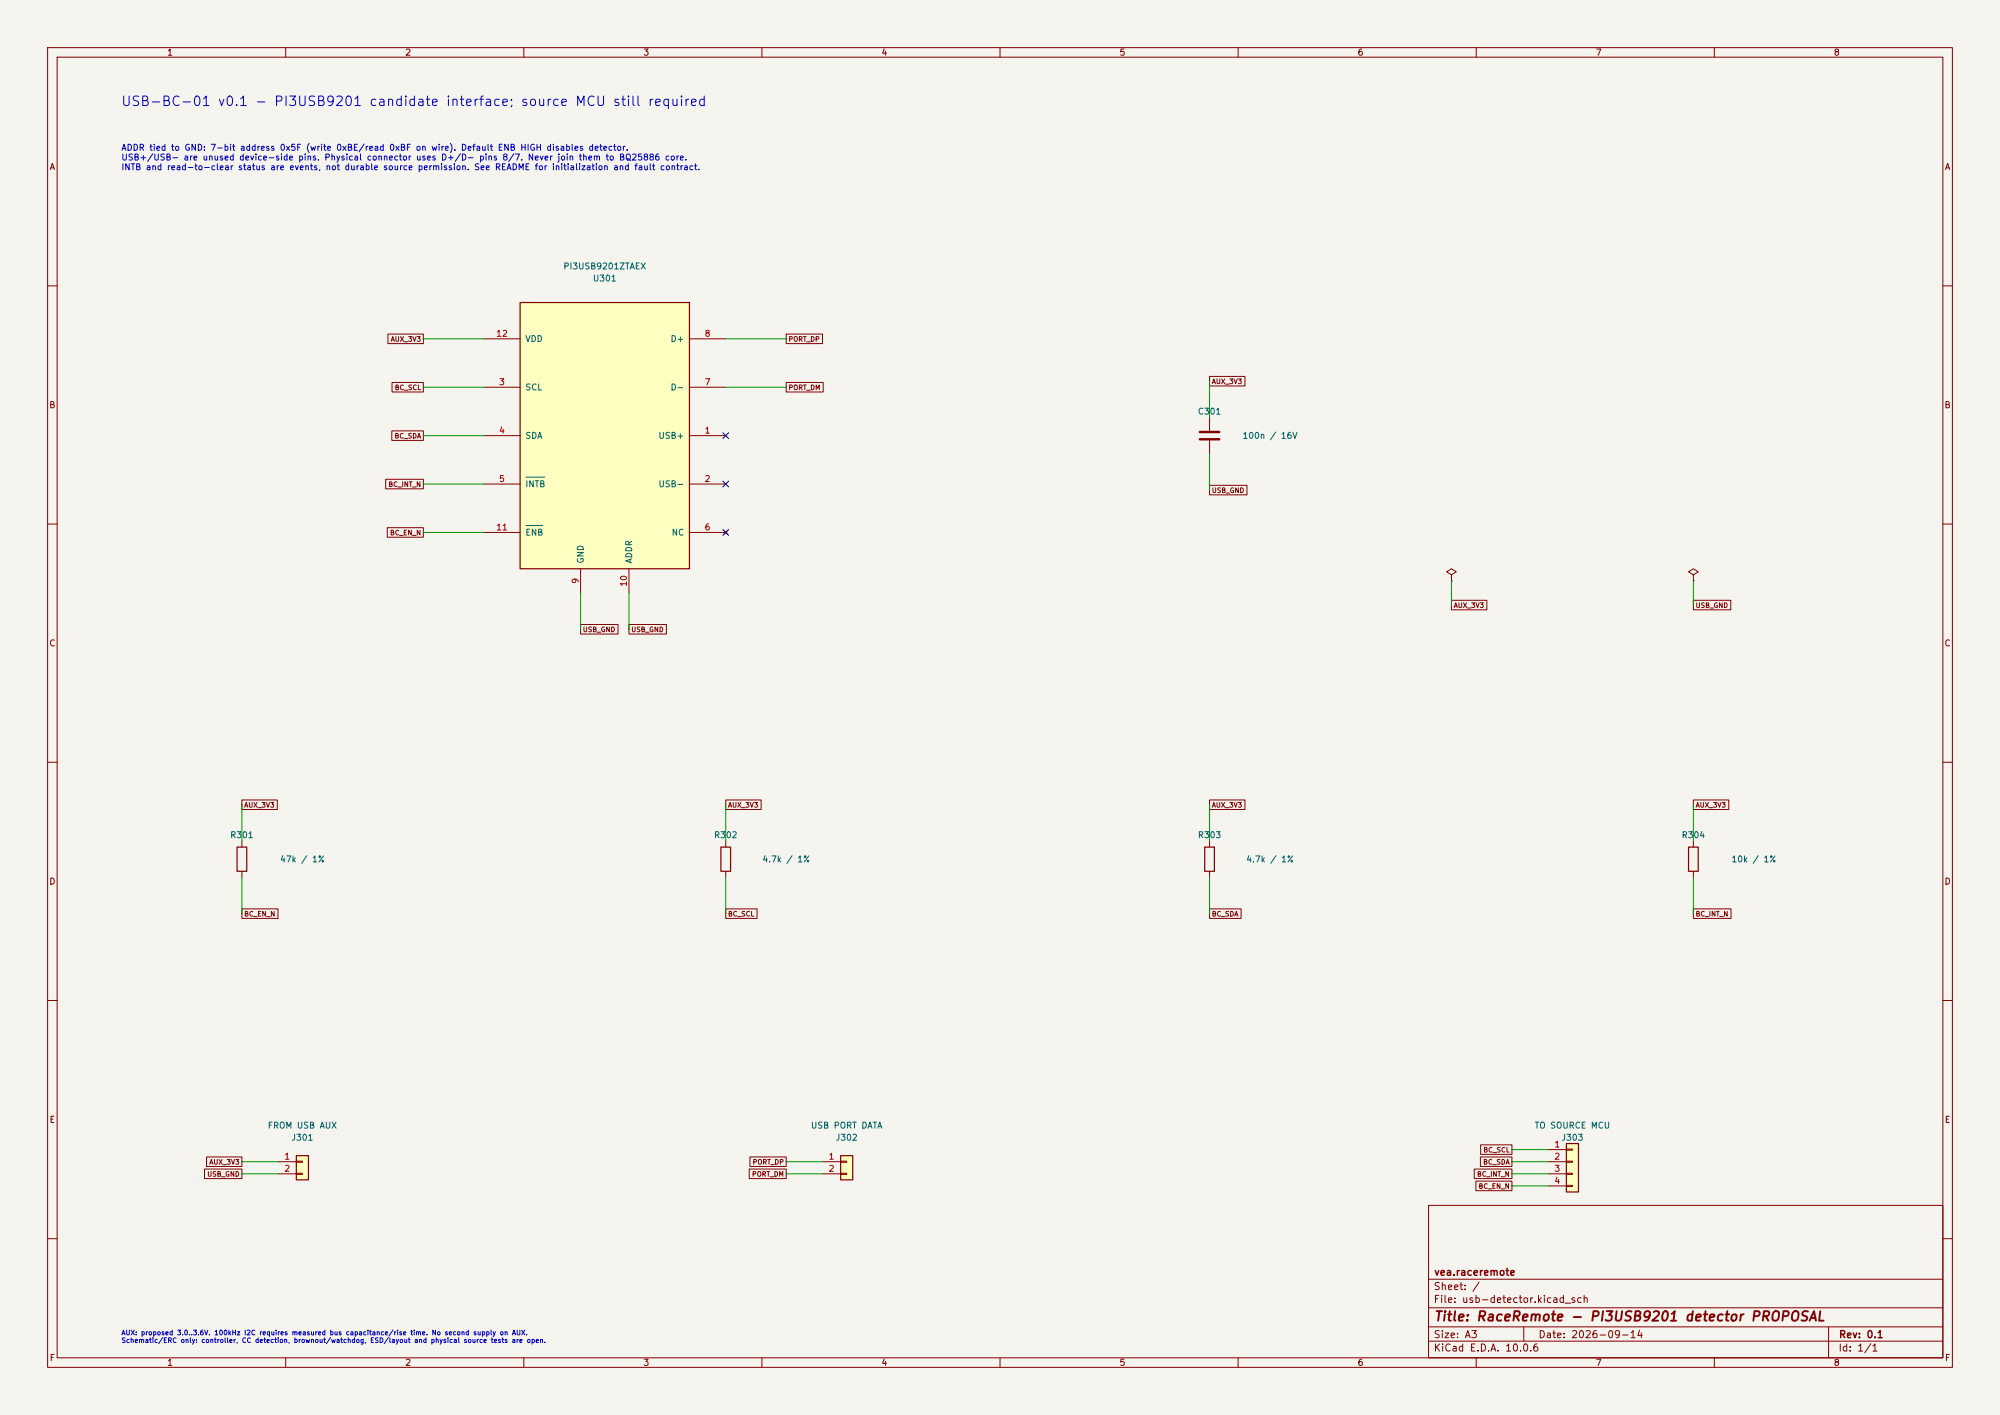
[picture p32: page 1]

INTB and read-to-clear status are events, not durable source permission. See README for initialization and fault contract. USB-BC-01 v0.1 - PI3USB9201 candidate interface; source MCU still required

ADDR tied to GND: 7-bit address 0x5F (write 0xBE/read 0xBF on wire). Default ENB HIGH disables detector. USB+/USB- are unused device-side pins. Physical connector uses D+/D- pins 8/7. Never join them to BQ25886 core.

vea.raceremote
Sheet: /
File: usb-detector.kicad_sch
Title: RaceRemote - PI3USB9201 detector PROPOSAL

AUX: proposed 3.0..3.6V. 100kHz I2C requires measured bus capacitance/rise time. No second supply on AUX. Schematic/ERC only: controller, CC detection, brownout/watchdog, ESD/layout and physical source tests are open.

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

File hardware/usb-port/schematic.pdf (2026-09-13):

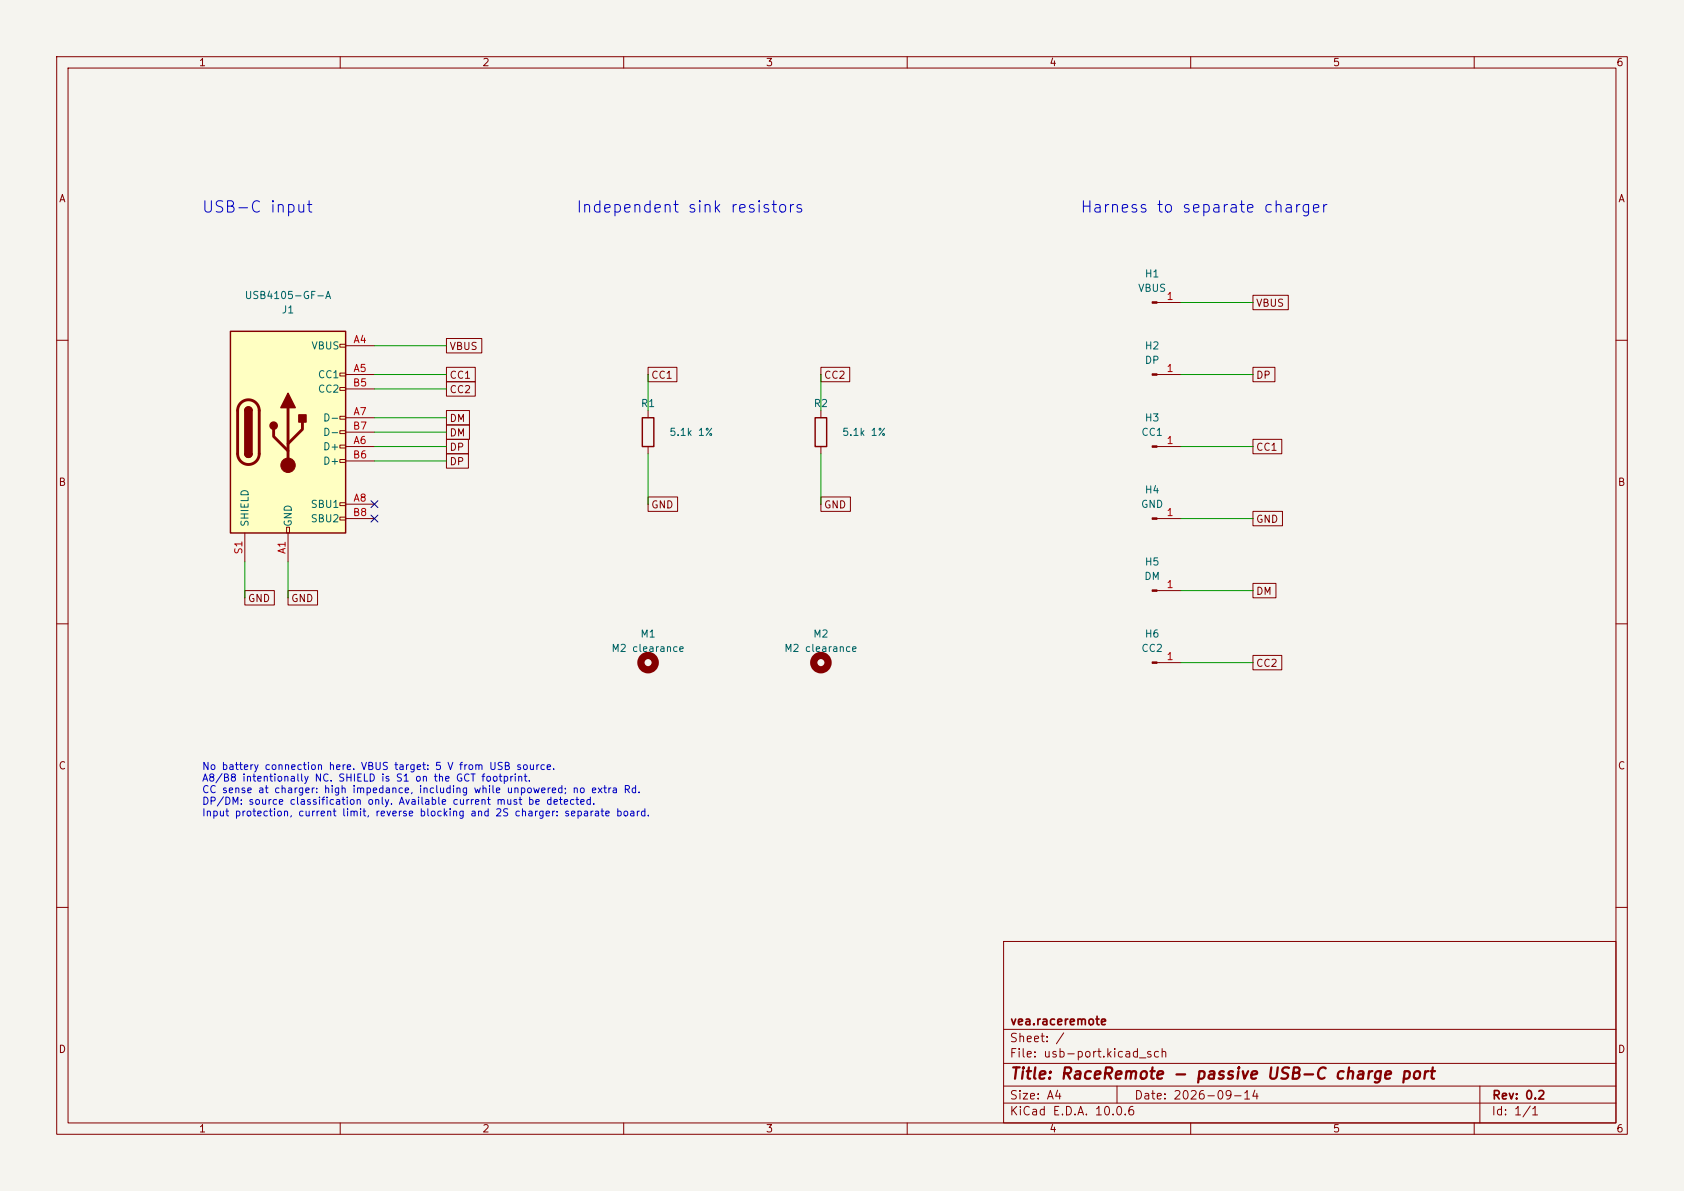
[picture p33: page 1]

Input protection, current limit, reverse blocking and 2S charger: separate board. USB-C input

vea.raceremote
Sheet: /
File: usb-port.kicad_sch
Title: RaceRemote - passive USB-C charge port

Size: A4 | Rev: 0.2
KiCad E.D.A. 10.0.6 | Id: 1/1

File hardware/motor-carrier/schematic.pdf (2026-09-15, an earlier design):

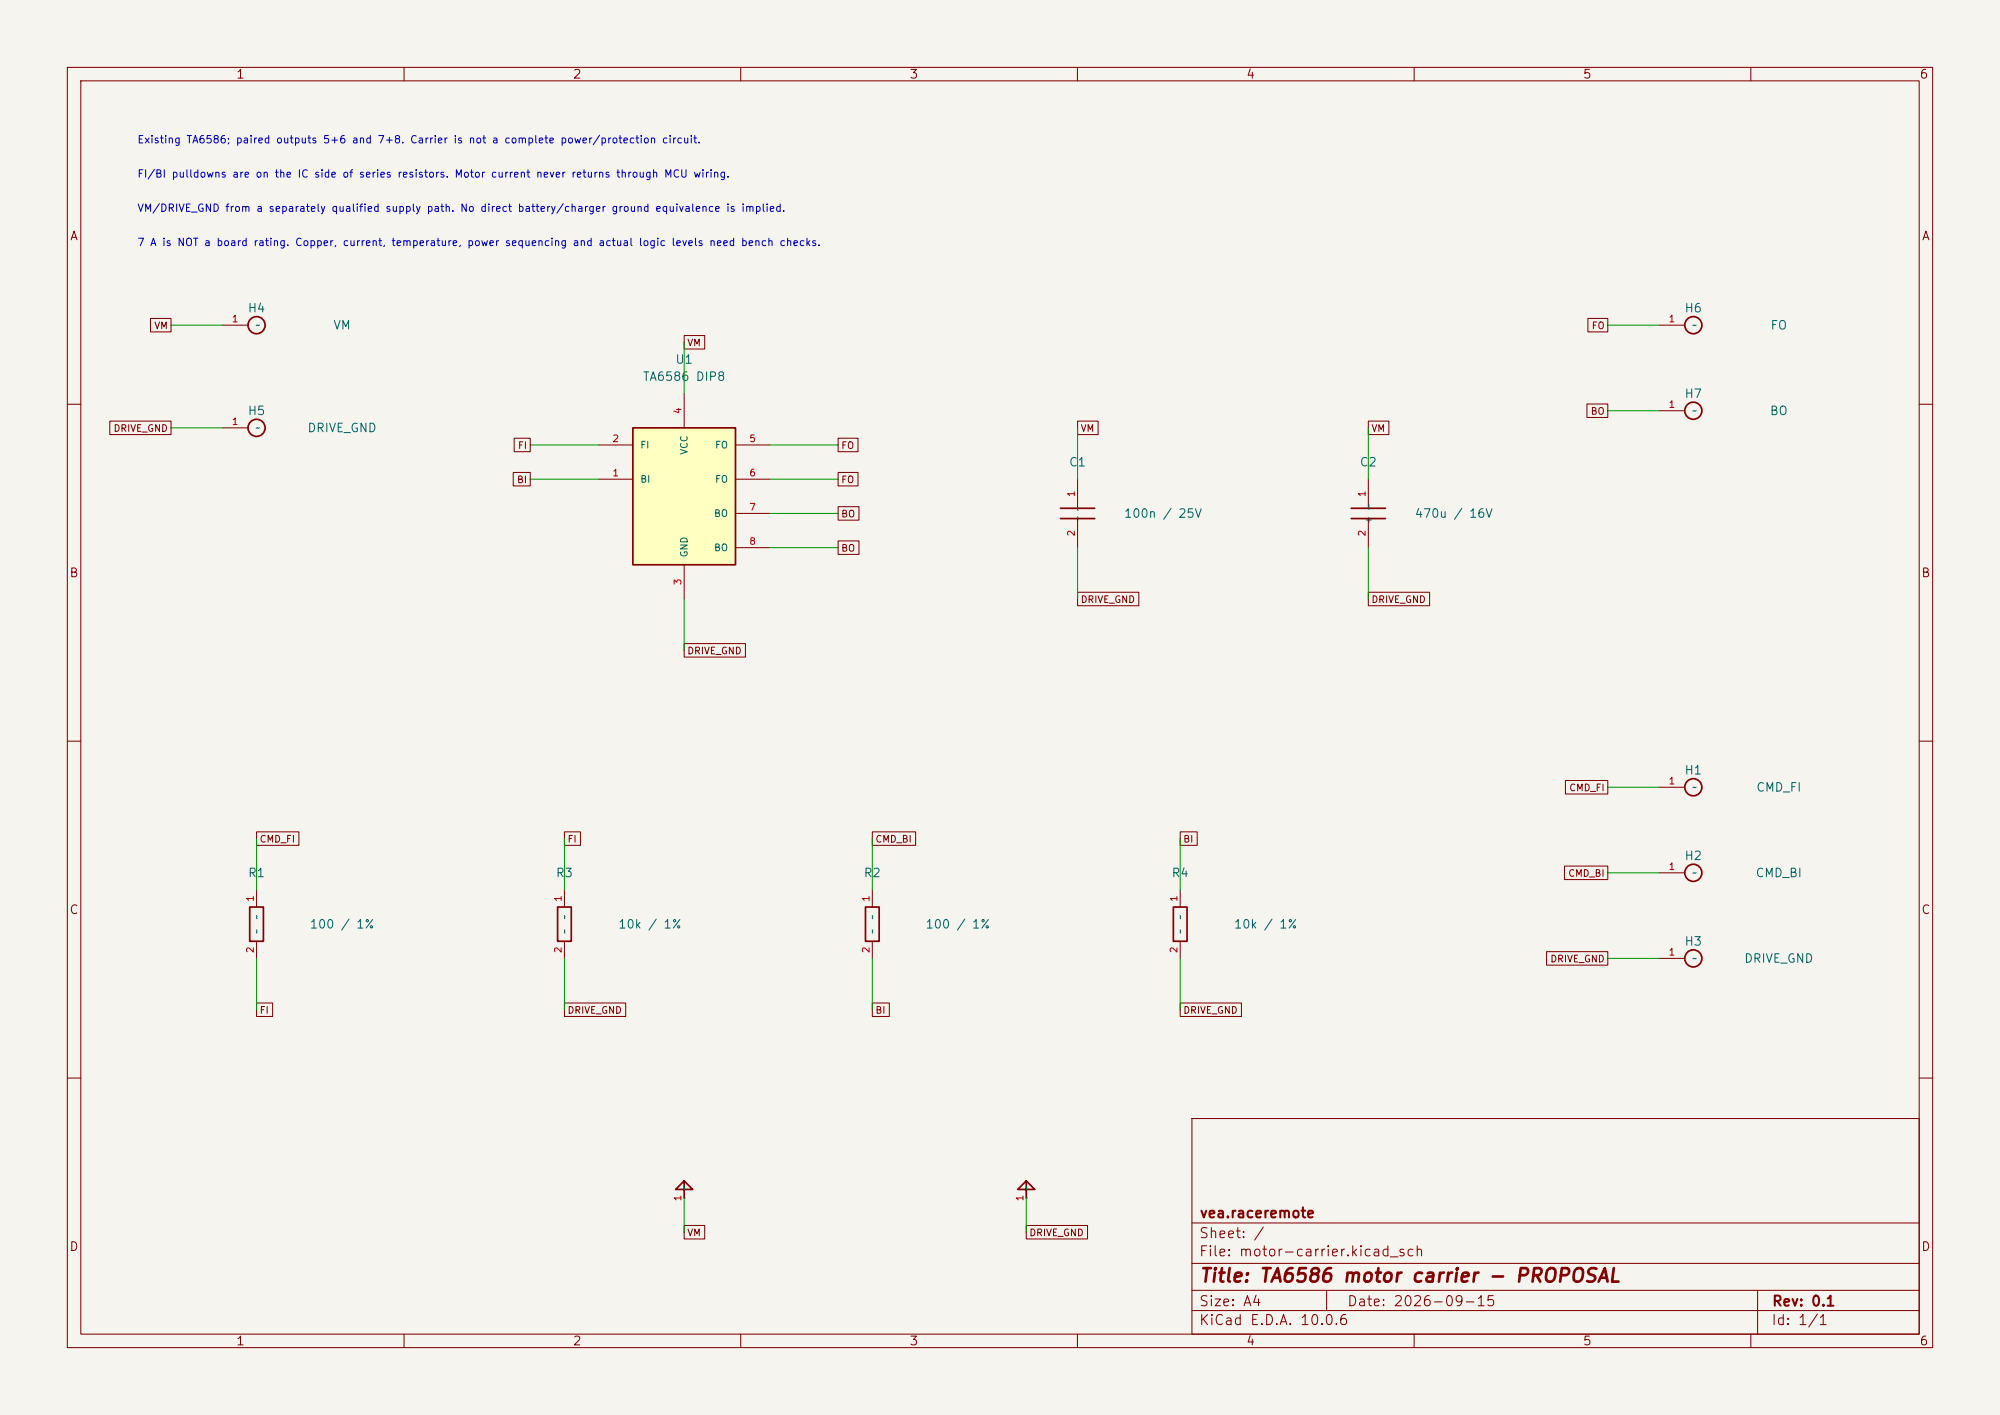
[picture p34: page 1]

VM/DRIVE_GND from a separately qualified supply path. No direct battery/charger ground equivalence is implied. FI/BI pulldowns are on the IC side of series resistors. Motor current never returns through MCU wiring. 7 A is NOT a board rating. Copper, current, temperature, power sequencing and actual logic levels need bench checks. Existing TA6586; paired outputs 5+6 and 7+8. Carrier is not a complete power/protection circuit.

vea.raceremote
Sheet: /
File: motor-carrier.kicad_sch
Title: TA6586 motor carrier - PROPOSAL

Size: A4 | Rev: 0.1
KiCad E.D.A. 10.0.6 | Id: 1/1

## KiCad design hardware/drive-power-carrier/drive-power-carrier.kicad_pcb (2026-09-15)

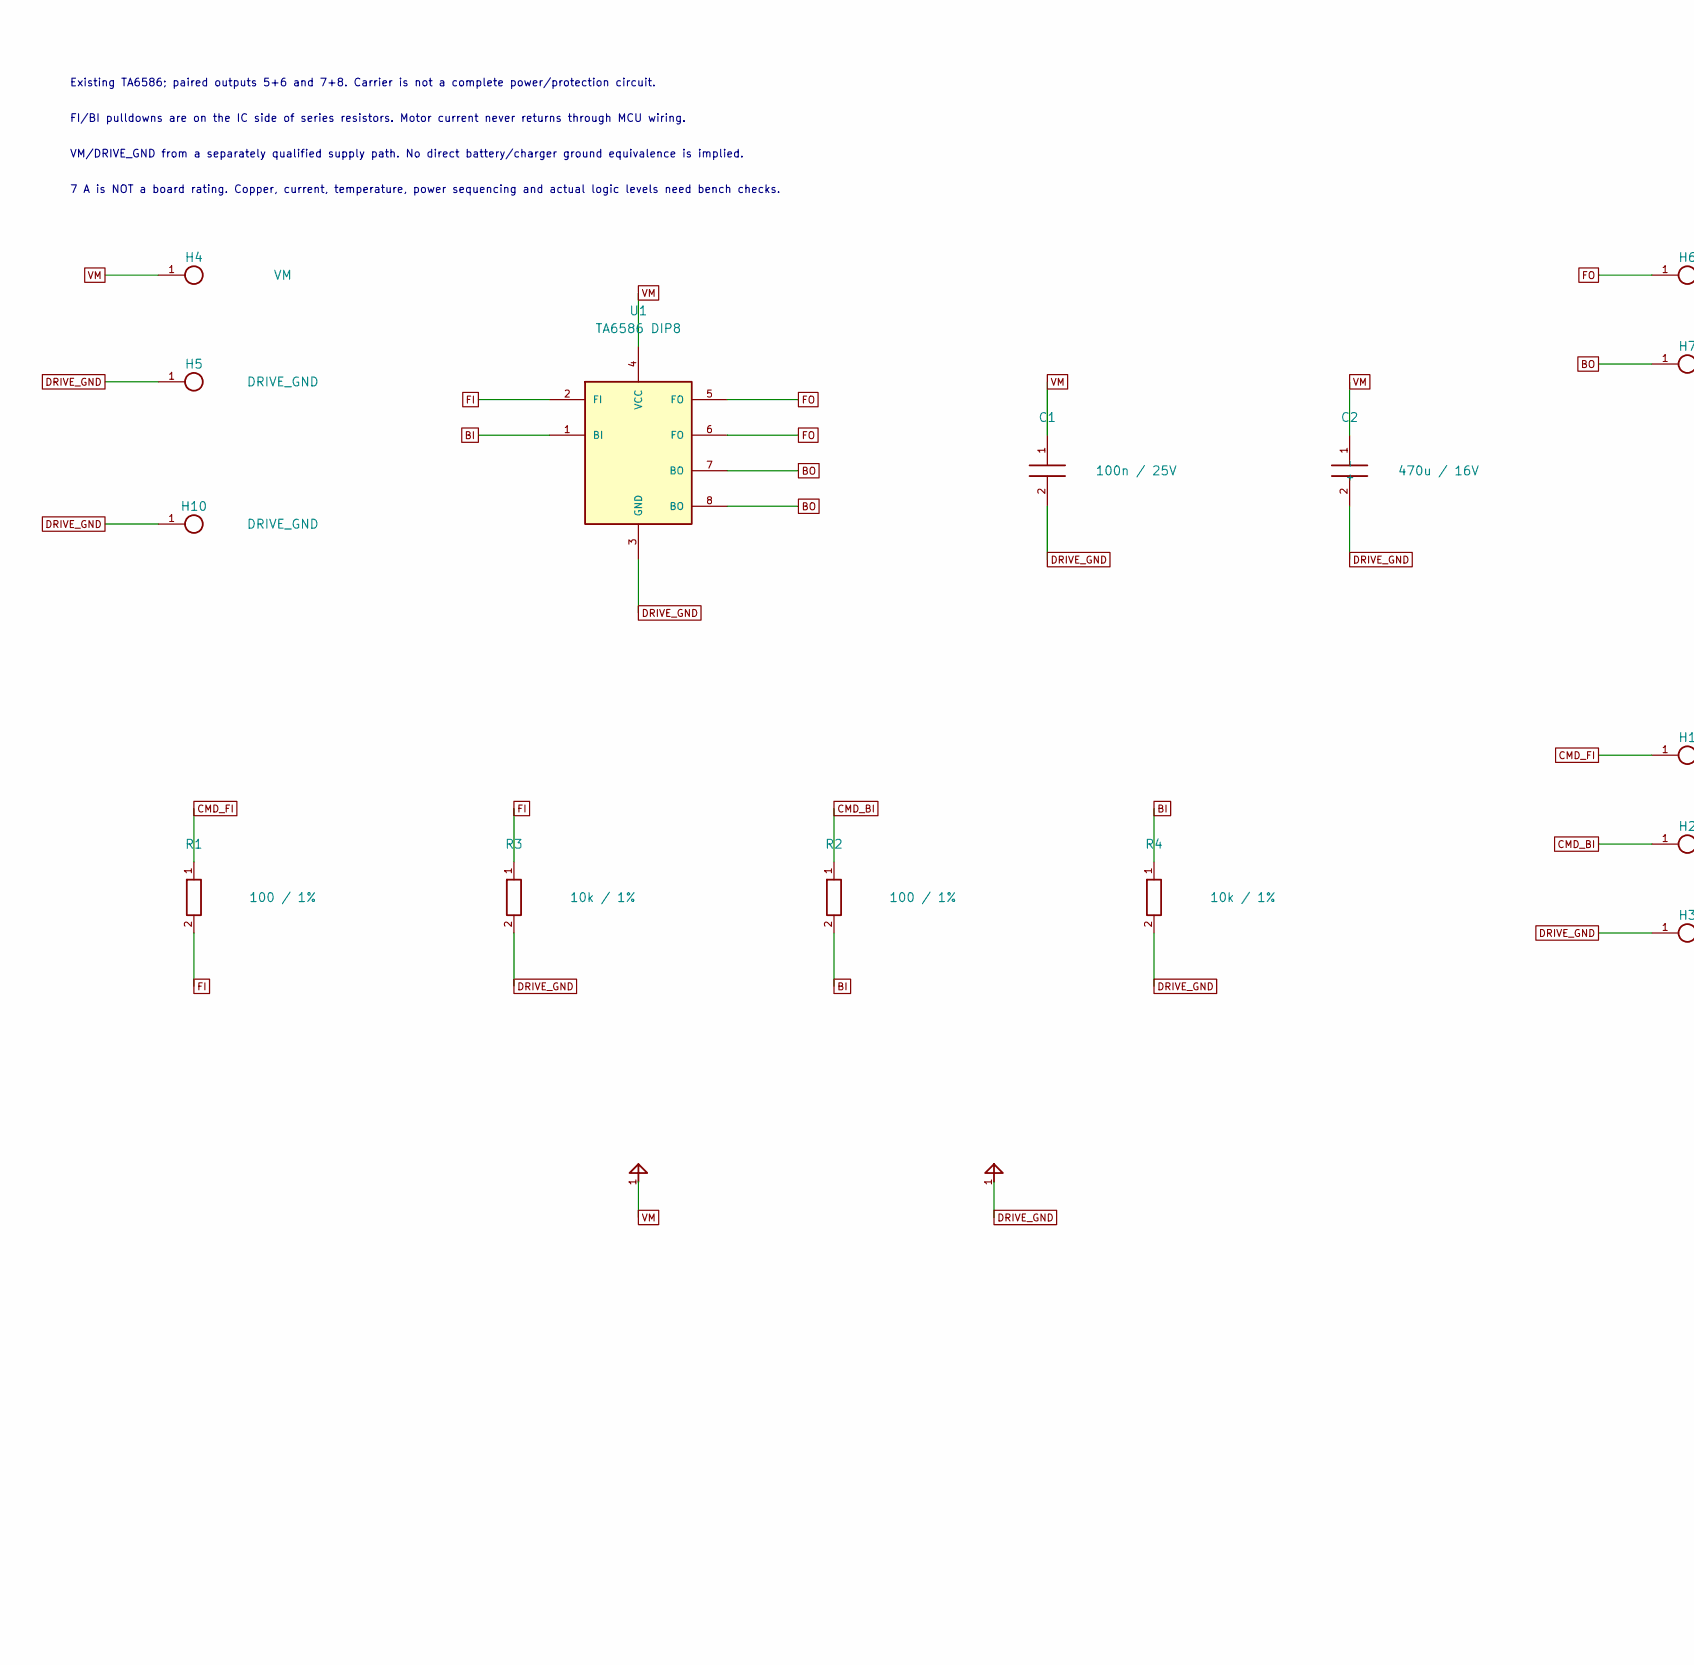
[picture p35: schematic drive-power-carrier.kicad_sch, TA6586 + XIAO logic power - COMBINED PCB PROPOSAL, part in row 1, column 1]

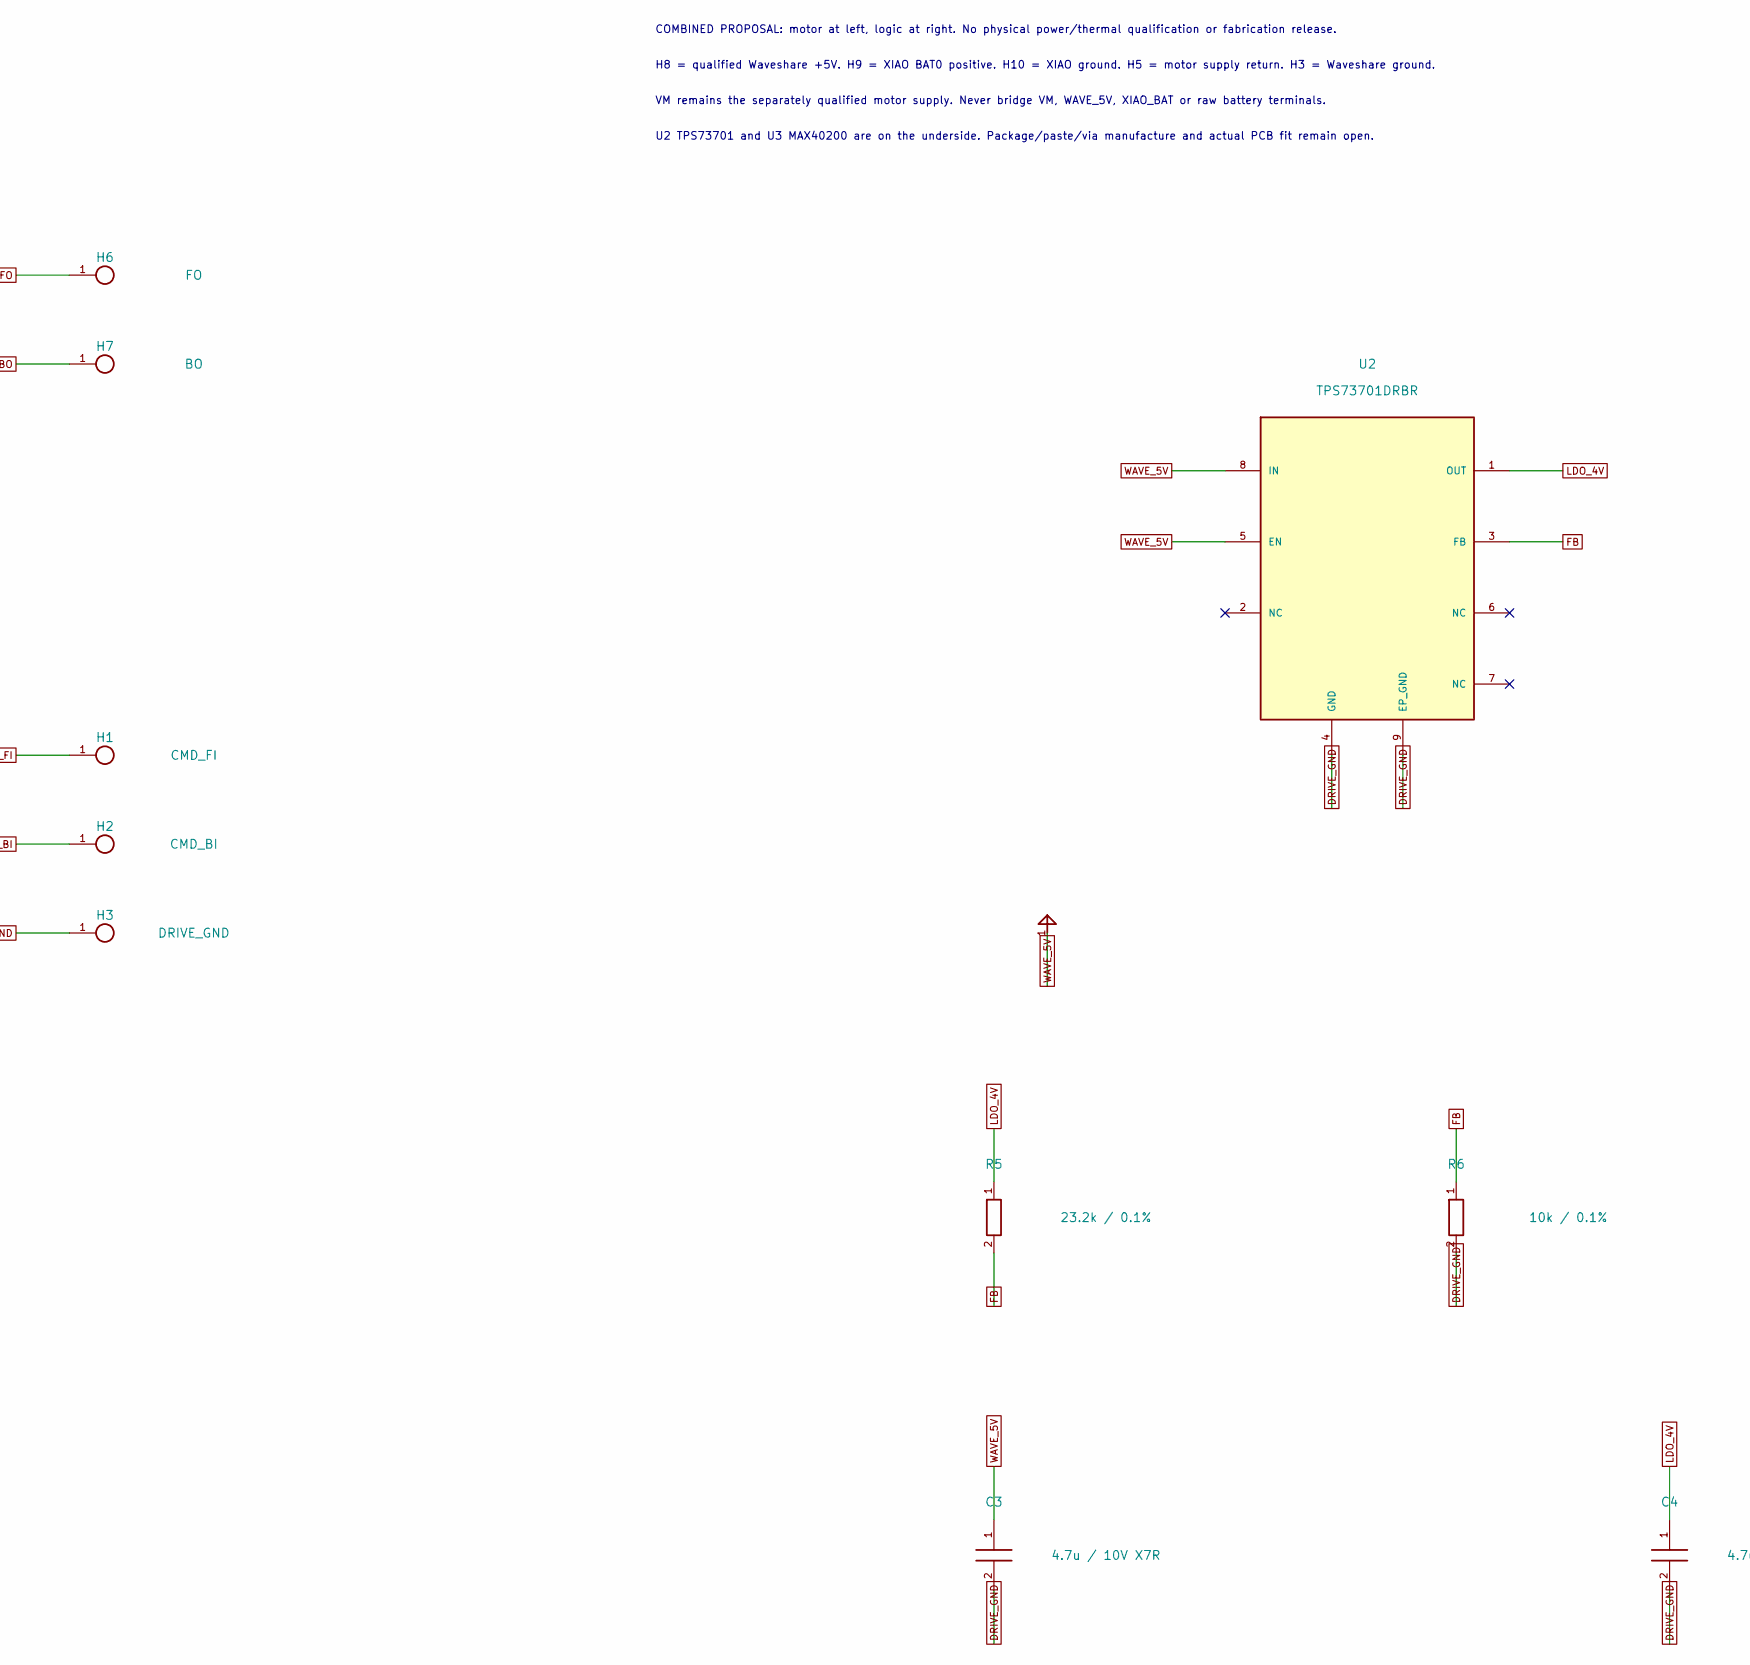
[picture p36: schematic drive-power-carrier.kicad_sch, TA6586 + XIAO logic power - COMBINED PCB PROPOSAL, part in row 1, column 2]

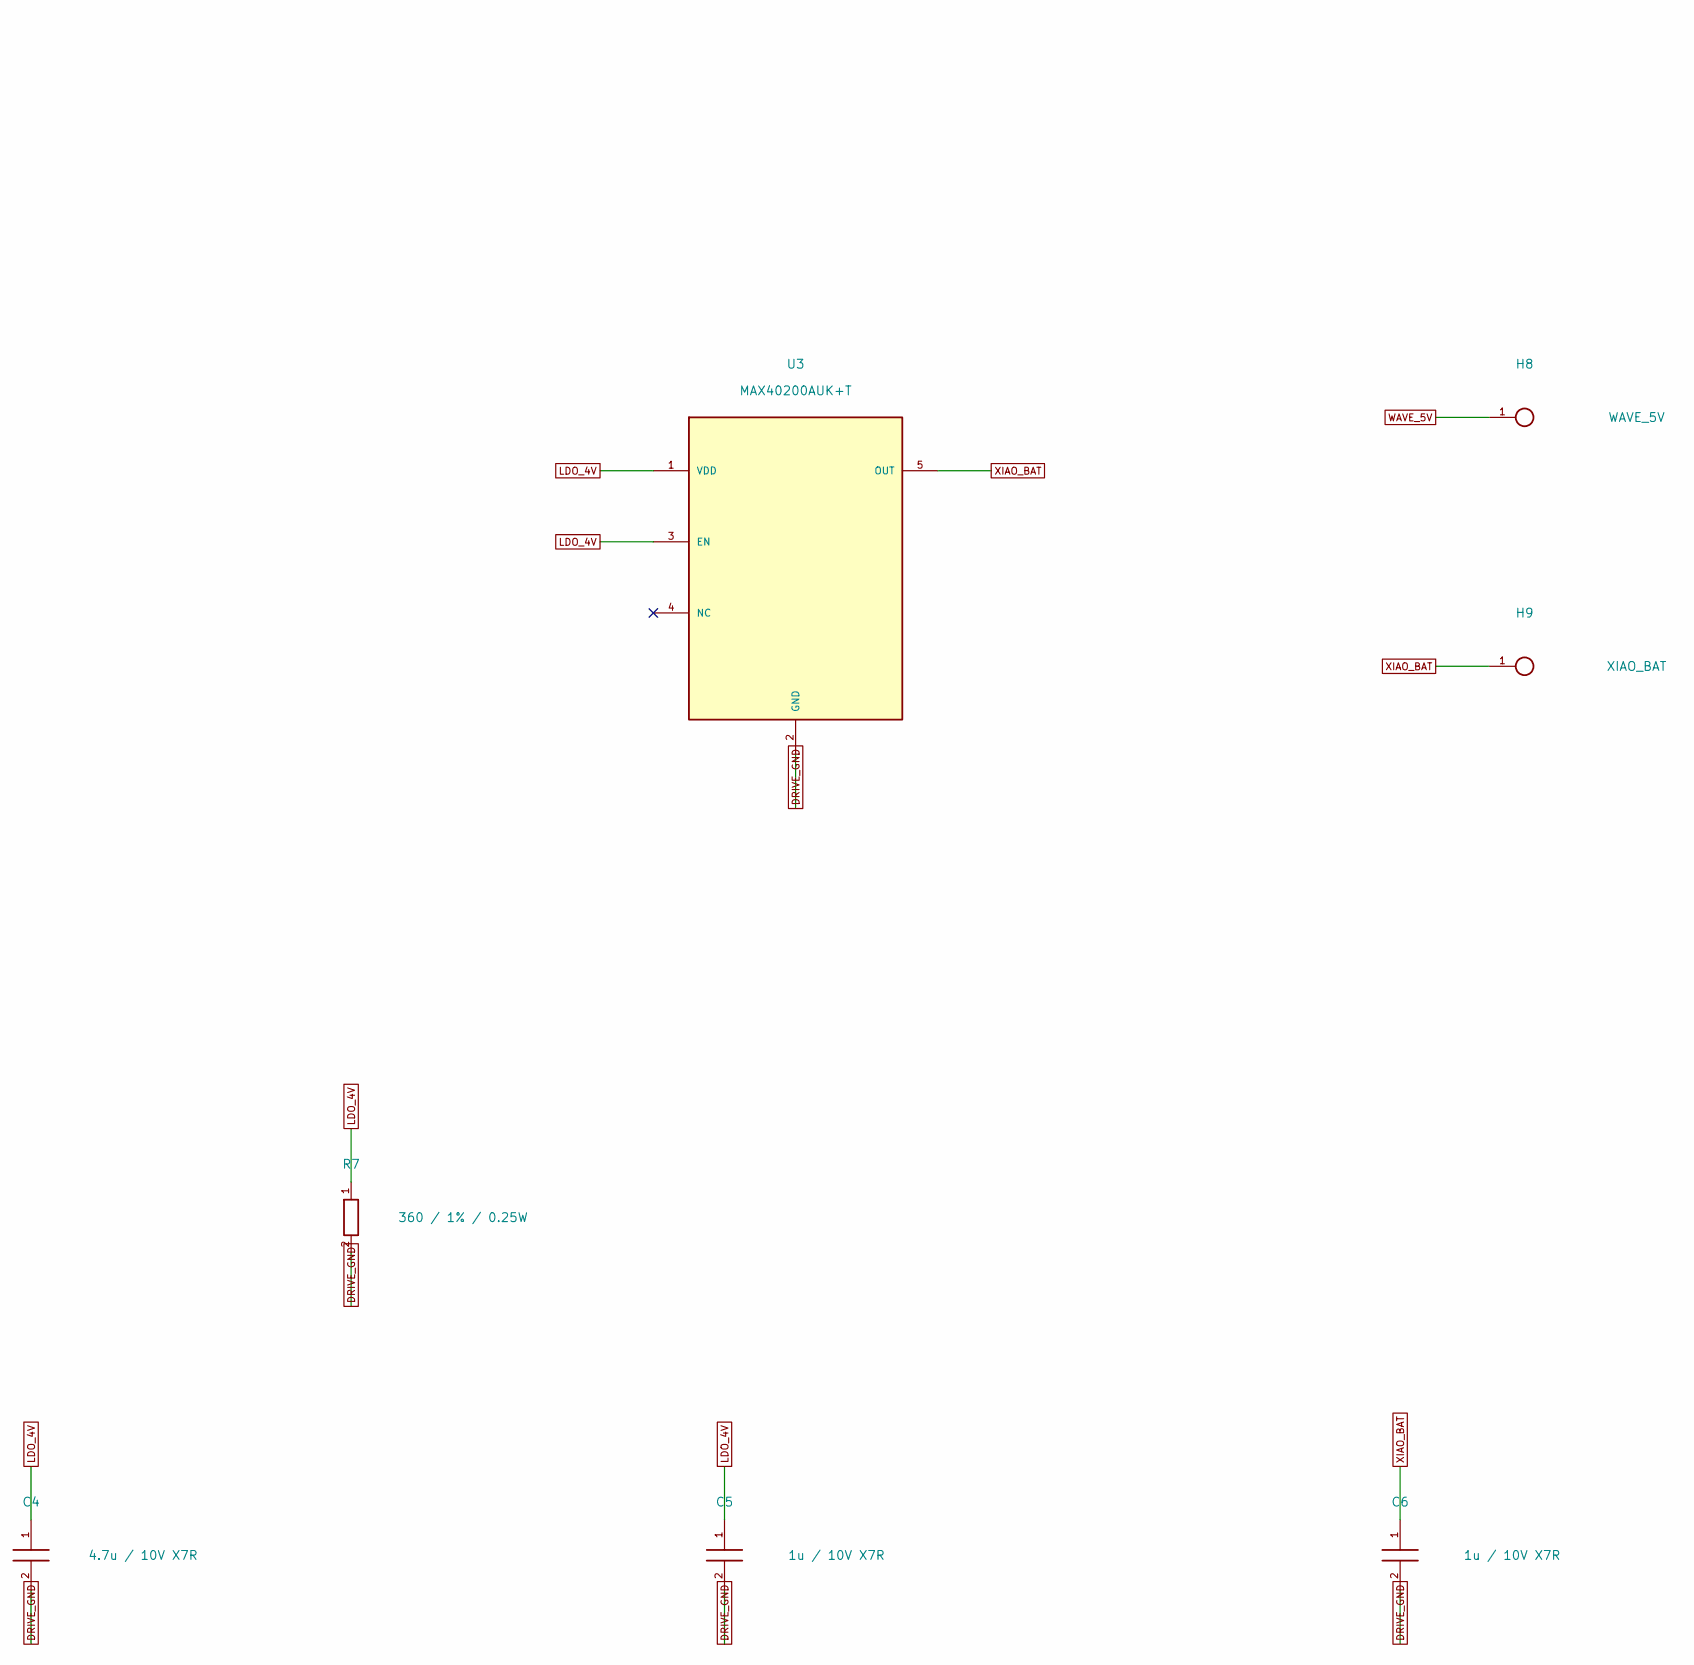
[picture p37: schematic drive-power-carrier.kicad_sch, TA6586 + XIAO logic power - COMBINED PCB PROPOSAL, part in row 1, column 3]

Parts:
C1: 100n / 25V; C_0805
C2: 470u / 16V; CP_D8_P3.5
C3: 4.7u / 10V X7R; C_0805_C3
C4: 4.7u / 10V X7R; C_0805_C4
C5: 1u / 10V X7R; C_0805_C5
C6: 1u / 10V X7R; C_0805_C6
H1: CMD_FI; WirePad_1mm
H2: CMD_BI; WirePad_1mm
H3, H5: DRIVE_GND; WirePad_1mm
H4: VM; WirePad_1mm
H6: FO; WirePad_1mm
H7: BO; WirePad_1mm
H8: WAVE_5V; WirePad_1mm_H8
H9: XIAO_BAT; WirePad_1mm_H9
H10: DRIVE_GND; WirePad_1mm_H10
R1, R2: 100 / 1%; R_0805
R3, R4: 10k / 1%; R_0805
R5: 23.2k / 0.1%; R_0805_R5
R6: 10k / 0.1%; R_0805_R6
R7: 360 / 1% / 0.25W; R_1206_R7
U1: TA6586 DIP8; TA6586_DIP8
U2: TPS73701DRBR; TPS73701_DRB_3x3_EP_U2
U3: MAX40200AUK+T; SOT23_5_ADI_90_0174_B_U3

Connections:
BI: R2.2, R4.1, U1.1 (BI)
BO: H7.1, U1.7 (BO), U1.8 (BO)
CMD_BI: H2.1, R2.1
CMD_FI: H1.1, R1.1
DRIVE_GND: C1.2, C2.2 (-), C3.2, C4.2, C5.2, C6.2, H3.1, H5.1, H10.1, R3.2, R4.2, R6.2, R7.2, U1.3 (GND), U2.4 (GND), U2.9 (EP_GND), U3.2 (GND)
FB: R5.2, R6.1, U2.3 (FB)
FI: R1.2, R3.1, U1.2 (FI)
FO: H6.1, U1.5 (FO), U1.6 (FO)
LDO_4V: C4.1, C5.1, R5.1, R7.1, U2.1 (OUT), U3.1 (VDD), U3.3 (EN)
VM: C1.1, C2.1 (+), H4.1, U1.4 (VCC)
WAVE_5V: C3.1, H8.1, U2.5 (EN), U2.8 (IN)
XIAO_BAT: C6.1, H9.1, U3.5 (OUT)

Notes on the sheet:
Existing TA6586; paired outputs 5+6 and 7+8. Carrier is not a complete power/protection circuit.
FI/BI pulldowns are on the IC side of series resistors. Motor current never returns through MCU wiring.
VM/DRIVE_GND from a separately qualified supply path. No direct battery/charger ground equivalence is implied.
7 A is NOT a board rating. Copper, current, temperature, power sequencing and actual logic levels need bench checks.
COMBINED PROPOSAL: motor at left, logic at right. No physical power/thermal qualification or fabrication release.
H8 = qualified Waveshare +5V. H9 = XIAO BAT0 positive. H10 = XIAO ground. H5 = motor supply return. H3 = Waveshare ground.
VM remains the separately qualified motor supply. Never bridge VM, WAVE_5V, XIAO_BAT or raw battery terminals.
U2 TPS73701 and U3 MAX40200 are on the underside. Package/paste/via manufacture and actual PCB fit remain open.

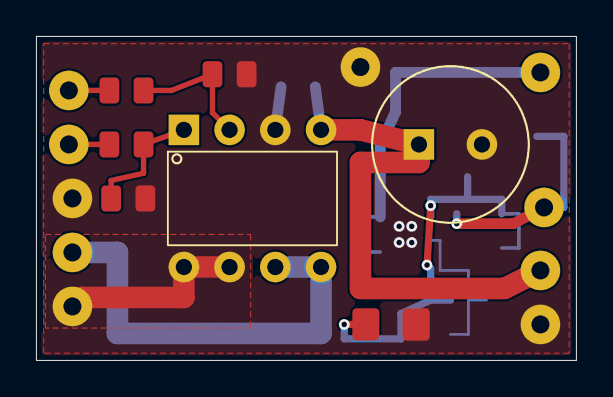
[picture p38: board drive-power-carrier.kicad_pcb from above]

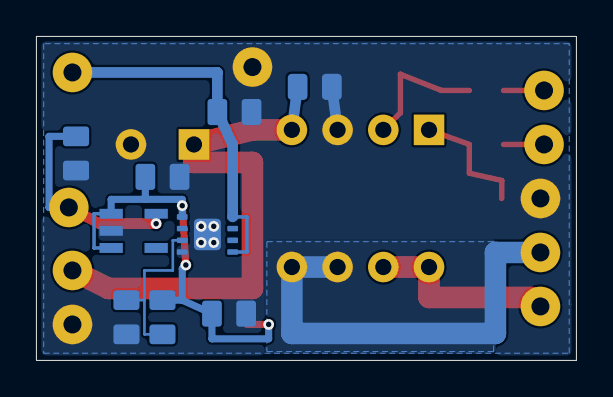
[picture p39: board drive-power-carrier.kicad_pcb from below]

Board: 2 copper layers, 30.0 x 18.0 mm, 26 parts (9 on the bottom side), 12 nets.

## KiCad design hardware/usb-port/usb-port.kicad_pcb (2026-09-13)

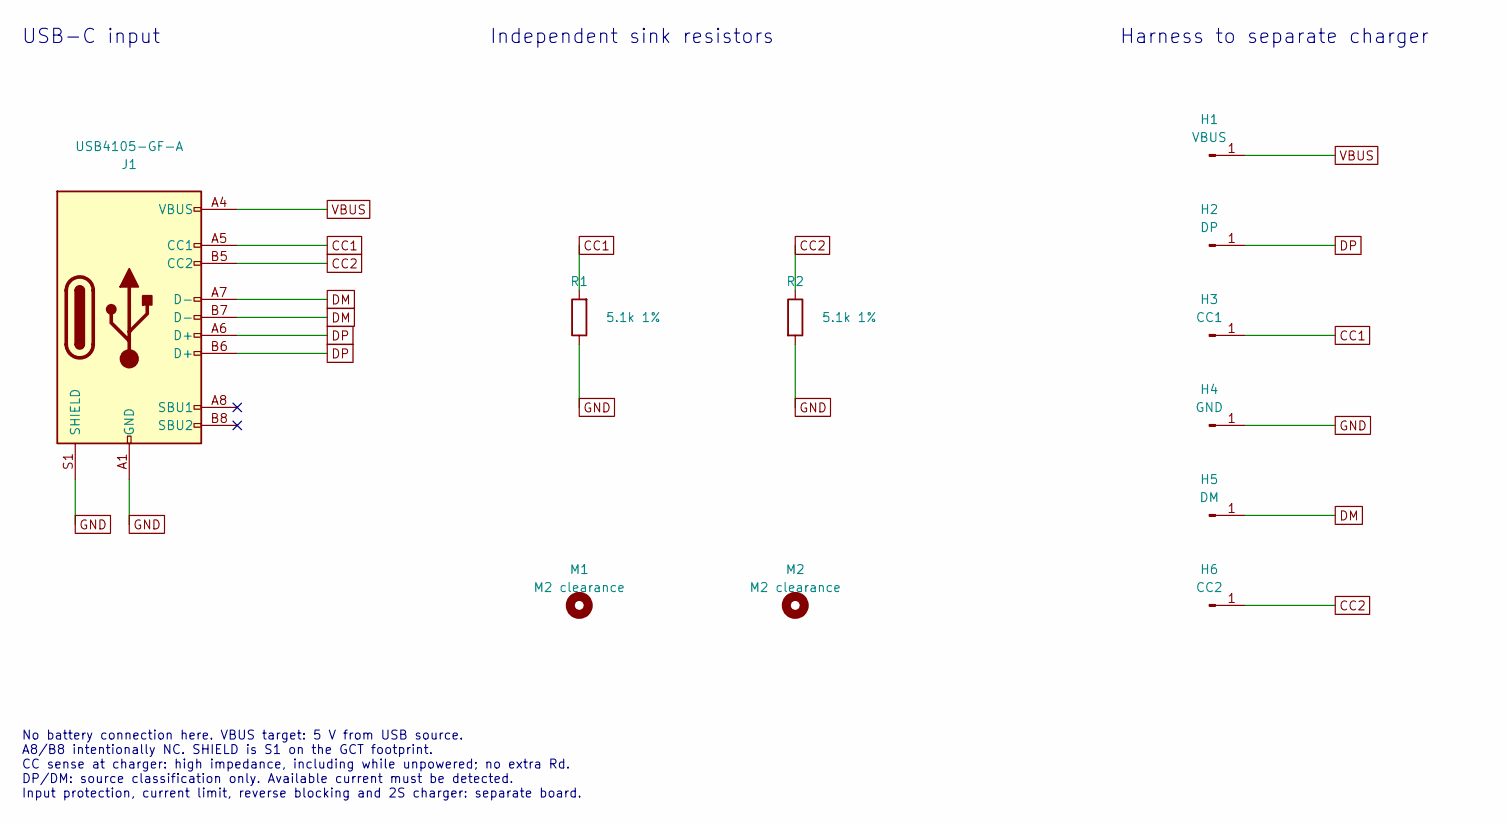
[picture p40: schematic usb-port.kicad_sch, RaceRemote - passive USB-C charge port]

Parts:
H1: VBUS; WirePad_D0.8mm
H2: DP; WirePad_D0.8mm
H3: CC1; WirePad_D0.8mm
H4: GND; WirePad_D0.8mm
H5: DM; WirePad_D0.8mm
H6: CC2; WirePad_D0.8mm
J1: USB4105-GF-A; USB_C_Receptacle_GCT_USB4105-xx-A_16P_TopMnt_Horizontal
M1, M2: M2 clearance; MountingHole_2.4mm
R1, R2: 5.1k 1%; R_0603_1608Metric

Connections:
CC1: H3.1, J1.A5 (CC1), R1.2
CC2: H6.1, J1.B5 (CC2), R2.1
DM: H5.1, J1.A7 (D-), J1.B7 (D-)
DP: H2.1, J1.A6 (D+), J1.B6 (D+)
GND: H4.1, J1.A1 (GND), J1.A12 (GND), J1.B1 (GND), J1.B12 (GND), J1.S1 (SHIELD), R1.1, R2.2
VBUS: H1.1, J1.A4 (VBUS), J1.A9 (VBUS), J1.B4 (VBUS), J1.B9 (VBUS)

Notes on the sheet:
USB-C input
Independent sink resistors
Harness to separate charger
No battery connection here. VBUS target: 5 V from USB source. A8/B8 intentionally NC. SHIELD is S1 on the GCT footprint. CC sense at charger: high impedance, including while unpowered; no extra Rd. DP/DM: source classification only. Available current must be detected. Input protection, current limi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

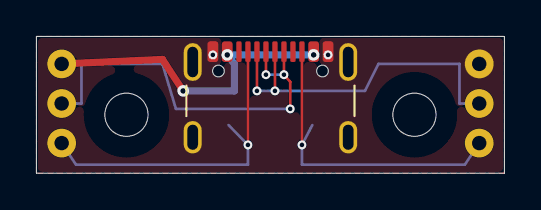
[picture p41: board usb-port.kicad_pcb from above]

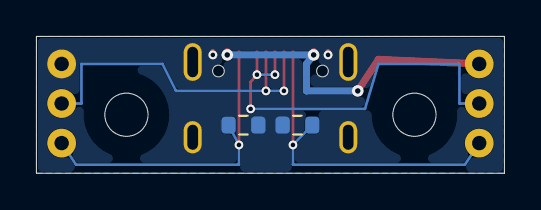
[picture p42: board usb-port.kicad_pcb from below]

Board: 2 copper layers, 26.0 x 7.6 mm, 11 parts (2 on the bottom side), 6 nets.

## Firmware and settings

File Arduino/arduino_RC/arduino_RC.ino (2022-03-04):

#include <CommandHandler.h>
#include <SoftwareSerial.h>
#include <GyverMotor.h>
#include <Servo.h>



Servo servo;
CommandHandler ch;
GMotor motor(DRIVER2WIRE, 9, 8, HIGH);

unsigned int readByte = 0;
unsigned int currentCommand = 0;

unsigned int purifiedValue = 0;
unsigned int purifiedCommand = 0;

unsigned int ENGINE_COMMAND = 3072;
unsigned int STEERING_WHEEL_COMMAND = 2048;

bool isSteeringWheelCommand(unsigned int command){
  return command == STEERING_WHEEL_COMMAND;
}

bool isEngineCommand(unsigned int command){
  return command == ENGINE_COMMAND;
}

bool isCommand(unsigned int command){
  return command != ch.NO_COMMAND_YET;
}

unsigned int getValue(unsigned int command) {
    return command & 1023;
}

unsigned int getCommand(unsigned int command) {
    return command & 3072;
}

void updateEnginge(unsigned int value){
  motor.setSpeed(value - 255);
}

void updateSteeringWheel(unsigned int value){
  servo.write(value);
}

void setup() {
  Serial.begin(9600);
  servo.attach(5);
  motor.setDirection(REVERSE);
  motor.setMode(FORWARD);
}

void loop() {
  if (Serial.available() > 0)
  {
    readByte = Serial.read();
    currentCommand = ch.tryGetCommand(readByte);
    
    if (isCommand(currentCommand)){
        purifiedCommand = getCommand(currentCommand);
        purifiedValue = getValue(currentCommand);
        
        if (isSteeringWheelCommand(purifiedCommand)){
          updateSteeringWheel(purifiedValue);
          digitalWrite(LED_BUILTIN, HIGH);
        } else if (isEngineCommand(purifiedCommand)){
          updateEnginge(purifiedValue);
          digitalWrite(LED_BUILTIN, LOW);
        }
    }
  }
}

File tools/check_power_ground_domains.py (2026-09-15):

"""Conductive-ground topology only; no transistor, charger or battery simulation."""
import hashlib
import itertools
import json
from pathlib import Path
from collections import deque
import xml.etree.ElementTree as ET

ROOT=Path(__file__).resolve().parents[1]


def path(edges,start,finish):
    adjacency={}
    for a,b,label in edges:
        adjacency.setdefault(a,[]).append((b,label))
        adjacency.setdefault(b,[]).append((a,label))
    queue=deque([(start,[])])
    visited={start}
    while queue:
        node,steps=queue.popleft()
        if node==finish:return steps
        for other,label in adjacency.get(node,[]):
            if other not in visited:
                visited.add(other);queue.append((other,steps+[{'from':node,'to':other,'connection':label}]))
    return None


def topology(protection_closed,drive_on,charge_attached,service_attached,shared_host,
             charge_ground='protected',raw_monitor_wire=False):
    edges=[
        ('PACK_P','PROTECTED_P','proposed common positive; fuse and positive cutoff not modelled'),
        ('PROTECTED_N','DRIVE_GND','proposed dedicated supply return to carrier H5'),
        ('DRIVE_GND','XIAO_GND','carrier H10 and GND0 wire'),
        ('DRIVE_GND','WAVE_OUT_GND','carrier H3 and Waveshare output wire'),
        ('DRIVE_GND','WAVE_IN_GND','proposed input return; wiring not yet built'),
        ('XIAO_GND','USB_SERVICE_GND','native XIAO service ground'),
        ('CHARGER_GND','USB_CHARGE_GND','proposed non-isolated charger input ground'),
        ('CHARGER_GND','PROTECTED_N' if charge_ground=='protected' else 'RAW_N','charger ground assignment'),
        ('RAW_N','RAW_MONITOR_GND','battery-side monitor ground; no signal crossing assigned')]
    if protection_closed:edges.append(('RAW_N','PROTECTED_N','ideal protection return contact'))
    if drive_on:edges.append(('PROTECTED_P','VM','ideal positive drive switch'))
    if charge_attached:edges.append(('USB_CHARGE_GND','HOST_CHARGE_GND','charge USB cable'))
    if service_attached:edges.append(('USB_SERVICE_GND','HOST_SERVICE_GND','service USB cable'))
    if shared_host:edges.append(('HOST_CHARGE_GND','HOST_SERVICE_GND','external common host/hub ground'))
    if raw_monitor_wire:edges.append(('RAW_MONITOR_GND','DRIVE_GND','incorrect direct raw-side reference wire'))
    return edges


def main():
    source=ROOT/'docs/evidence/drive-power-carrier-v03/netlist.xml'
    nets=ET.parse(source).findall('.//nets/net')
    ground=next(n for n in nets if n.attrib['name']=='DRIVE_GND')
    ground_pins={(n.attrib['ref'],n.attrib['pin']) for n in ground.findall('node')}
    assert {('H3','1'),('H5','1'),('H10','1'),('U1','3')}.issubset(ground_pins)
    for ref,expected in [('H4','VM'),('H8','WAVE_5V'),('H9','XIAO_BAT')]:
        found=[n.attrib['name'] for n in nets for pin in n.findall('node') if pin.attrib['ref']==ref]
        assert found==[expected],(ref,found)
    rows=[]
    for state in itertools.product([False,True],repeat=5):
        closed,on,charge,service,shared=state
        edges=topology(*state)
        return_path=path(edges,'RAW_N','PROTECTED_N')
        supply_path=path(edges,'PACK_P','VM')
        assert (return_path is not None)==closed
        assert (supply_path is not None)==on
        rows.append(dict(protection_closed=closed,drive_on=on,charge_usb=charge,service_usb=service,
                         shared_host=shared,raw_to_protected_ground_path=return_path,
                         pack_positive_to_VM_path=supply_path))
    # A concrete miswire can defeat an otherwise open return contact through a
    # real cable path. Keep drive OFF here: opening only positive does not isolate grounds.
    example_state=(False,False,True,True,True)
    wrong=path(topology(*example_state,charge_ground='raw'),'RAW_N','PROTECTED_N')
    assert wrong and any(s['connection']=='external common host/hub ground' for s in wrong)
    no_service=path(topology(False,False,True,False,True,charge_ground='raw'),'RAW_N','PROTECTED_N')
    assert no_service is None
    wrong_monitor=path(topology(False,False,False,False,False,raw_monitor_wire=True),'RAW_N','PROTECTED_N')
    assert wrong_monitor
    # Exhaustively identify, rather than hide, the state dependence of this miswire.
    bad_cases=[]
    for on,charge,service,shared in itertools.product([False,True],repeat=4):
        bypass=path(topology(False,on,charge,service,shared,charge_ground='raw'),'RAW_N','PROTECTED_N')
        assert (bypass is not None)==(charge and service and shared)
        if bypass is not None:bad_cases.append(dict(drive_on=on,charge_usb=charge,service_usb=service,shared_host=shared))
    inputs=[Path(__file__),source,ROOT/'docs/xiao-usb-power.md',ROOT/'hardware/pack-balancer/README.md',ROOT/'docs/charge-sense-paths.md']
    report={'contract':'POWER-GROUND-01 v0.1','date':'2026-09-15',
            'status':'proposed boundary condition; complete power circuit NOT qualified',
            'model':'undirected galvanic wiring and ideal contacts; not voltage/current or protection-FET simulation',
            'carrier_ground_pins_verified':sorted([list(x) for x in ground_pins]),
            'proposed_protected_bus_cases':rows,'raw_charger_ground_counterexample':wrong,
            'raw_ground_miswire_bypass_states':bad_cases,'direct_raw_monitor_counterexample':wrong_monitor,
            'omitted_paths':['battery sources and midpoint conductors','charger CBSET/MID/BAT internal paths',
                             'MOSFET body diodes, leakage, shutdown and transient behaviour',
                             'sensor signal ESD/protection paths','shield/chassis connections not yet assigned',
                             'positive-rail converter and GPIO backfeed, fuse/current limits'],
            'physical_tests':False,'ready_to_wire_LW':False,
            'source_sha256':{p.relative_to(ROOT).as_posix():hashlib.sha256(p.read_bytes()).hexdigest() for p in inputs}}
    out=ROOT/'docs/evidence/power-ground-v01.json'
    out.write_text(json.dumps(report,indent=2)+'\n',encoding='utf-8',newline='\n')
    print('Verified 32 proposed contact states and16 miswire states; USB and raw-monitor bypass paths exposed.')
    print('Complete protection/power integration: NOT qualified.')


if __name__=='__main__':main()

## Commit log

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2021-08-26 Исправлено положение текста на экране поиска Bluetooth устройств
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2021-10-13 Исправлена логика CompoundCommandCreator.kt, добавлен тесты для класса.
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2023-03-02 fix action button color
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2026-09-13 docs: record RC car requirements, hardware research and commit policy
    [parts.csv]
2026-09-13 Use vea.raceremote and add Android ESP32 control bench
    [parts.csv]
2026-09-13 Document actuator bench wiring and source a local antenna candidate
    [parts.csv]
2026-09-13 Model transverse battery placement and extraction in zcar
    [battery-dummy.stl, battery-layout.scad]
2026-09-13 Record preferred-store camera offer and sensor delivery limitations
    [parts.csv]
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2026-09-13 Model removable battery supports and guards for zcar fit testing
    [battery-end-guard.stl, battery-holder.scad, battery-support.stl]
2026-09-13 Identify affordable 2S motor and servo offers for drive prototype
    [parts.csv]
2026-09-13 docs: prepare static TA6586 input and output check
    [ta6586-measurement-template.csv]
2026-09-13 docs: compare available 2S to 5V power modules
    [parts.csv]
2026-09-13 docs: prepare bench purchase shortlist and clarify CAD scope
    [parts.csv]
2026-09-13 cad: assemble chassis packaging study with offline 3D viewer
    [assembly.scad, electronics-carrier.stl, zcar-aligned.stl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]
2026-09-13 Add body-constrained adjustable CAD and candidate purchase references
    [adjustable-camera_mount.stl, adjustable-layout-carrier.stl, adjustable-layout.scad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]
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2026-09-13 Document XIAO wiring proposal and verified AliExpress offer
    [parts.csv]
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2026-09-13 docs: record charger offers and battery swap startup constraints
    [charge-parts.csv]
2026-09-13 cad: add side USB-C port packaging and clearance checks
    [charge-parts.csv, usb-port-base.stl, usb-port-pcb.stl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]
2026-09-13 hardware: route USB-C port PCB and reconcile CAD with footprint
    [bom.csv, usb-port-base.stl, usb-port-pcb.scad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]
2026-09-13 hardware: add USB-C port schematic and verify PCB parity
    [usb-port.kicad_pcb, usb-port.kicad_sch]
2026-09-13 hardware: design and check BQ25886 charging core
    [bom.csv, charge-core.kicad_sch]
2026-09-13 cad: add removable USB-C lid and print-fit coupons
    [charge-parts.csv, usb-port-bezel-coupon-print.stl, usb-port-cover-print.stl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]
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2026-09-14 cad: locate SG90 frame interference and document sample fit dimensions
    [frame.stl, interference.stl, servo-clearance-viewer.json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]
2026-09-14 docs: define USB source qualification gaps and price detector candidates
    [charge-parts.csv]
2026-09-14 hardware: add default-off TPS25200 USB input gate schematic
    [bom.csv, charge-parts.csv, usb-input-gate.kicad_sch]
2026-09-14 hardware: add independent USB auxiliary supply for source detection
    [bom.csv, charge-parts.csv, usb-input-gate.kicad_sch]
2026-09-14 hardware: isolate charger detection from external USB data lines
    [bom.csv, charge-core.kicad_sch, charge-parts.csv]
2026-09-14 hardware: add PI3USB9201 charger detector interface candidate
    [bom.csv, charge-parts.csv, usb-detector.kicad_sch]
2026-09-14 hardware: compare charger variants with shared source MCU
    [charge-parts.csv, charger-mcu-pins.csv]
2026-09-14 hardware: quantify charger overcurrent detection candidate and costs
    [charge-parts.csv]
2026-09-14 hardware: add fault-cleared charge permit latch candidate
    [bom.csv, charge-parts.csv, charge-permit.kicad_sch]
2026-09-14 hardware: add conditional charger CD inhibit candidate
    [bom.csv, charge-parts.csv, charge-permit.kicad_sch]
2026-09-14 hardware: regulate charger inhibit bias independently from AUX
    [bom.csv, charge-parts.csv, charge-permit.kicad_sch]
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2026-09-14 hardware: add charger MCU interface and default-low request stages
    [bom.csv, charge-parts.csv, charge-permit.kicad_sch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]
2026-09-14 hardware: add latched charge overcurrent detector and shunt candidate
    [bom.csv, charge-overcurrent.kicad_sch, charge-parts.csv]
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2026-09-15 docs: confirm DT838 voltage mode and battery replacement
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2026-09-15 Add detailed CAD packaging with reference models and clearance checks
    [adjustable-band.stl, adjustable-battery.stl, adjustable-camera_fasteners.stl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]
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2026-09-15 Add removable XIAO cradle and correct service USB access
    [cap.stl, cap_print.stl, cradle.stl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]
2026-09-15 Add integral wire guides and recheck current service motions
    [cap.stl, cap_print.stl, harness-guides-assembly.scad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]
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2026-09-15 Add TA6586 carrier PCB and component-level CAD fit study
    [C1.stl, C2.stl, C2lead1.stl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]
2026-09-15 Add removable motor carrier holder and printable fit gauge
    [clamp.stl, clamp_print.stl, motor-carrier-mount-v01.json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]
2026-09-15 Route XIAO motor control leads from vendor pad coordinates
    [BI.stl, FI.stl, GND.stl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]
2026-09-15 Prepare motor holder 3MF fit kit and record deferred printing
    [motor-print-kit-v01.json, print-kit.3mf]
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2026-09-15 Prepare USB-only static TA6586 fixture and measurement procedure
    [ta6586-usb-measurement-template.csv]
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2026-09-15 Explore XIAO supply from shared 5V with service USB isolation
    [bom.csv, connections.csv, xiao-logic-power.kicad_sch]
2026-09-15 Remove XIAO USB sense dependency with MAX40200 reverse blocking
    [bom.csv, connections.csv, parts.csv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]
2026-09-15 Add combined motor and XIAO power carrier PCB proposal with CAD fit evidence
    [C3.stl, C4.stl, C5.stl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]
2026-09-15 Correct MAX40200 footprint and clearance reserve from reviewed manufacturer drawings
    [C5.stl, H9.stl, U3.stl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]
2026-09-15 Route XIAO rear power pads through cradle and verify body and battery service
    [BAT.stl, GND.stl, cradle.stl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]
2026-09-15 Route Waveshare output pair to combined carrier and verify service clearance
    [5V.stl, GND.stl]
2026-09-15 Evaluate keyed SM logic connector fit and record prewired half sourcing
    [parts.csv, sm-envelope.stl]
2026-09-15 Model soldered logic power pair and tray lacing with explicit clearance limits
    [5V.stl, GND.stl, parts.csv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]
2026-09-15 Route motor lead pair and expose terminal clearance conflict with matched suspension solids
    [BO.stl, FO.stl, motor-harness-v01.json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]
2026-09-15 Add dedicated XIAO ground landing and free traction input return
    [GND.stl, H10.stl, added-power-and-pcb.step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]
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2026-09-15 Reset video session when switching control target and verify on Samsung
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2026-09-15 Record Samsung smoke and servo bundle packaging reserve
    [bundle.stl, old-bundle.stl, servo-bundle-v01.json]
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2026-09-15 Route separate servo power pair from Waveshare header
    [GND.stl, VOUT.stl, servo-power-v01.json]
2026-09-15 Restrain servo pair in existing cap with removable lacing
    [GND.stl, VOUT.stl, cord.stl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]
2026-09-15 Package current electronics holders and PCB fit gauge
    [electronics-fit.3mf, pcb_clamp.stl, pcb_gauge.stl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]
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

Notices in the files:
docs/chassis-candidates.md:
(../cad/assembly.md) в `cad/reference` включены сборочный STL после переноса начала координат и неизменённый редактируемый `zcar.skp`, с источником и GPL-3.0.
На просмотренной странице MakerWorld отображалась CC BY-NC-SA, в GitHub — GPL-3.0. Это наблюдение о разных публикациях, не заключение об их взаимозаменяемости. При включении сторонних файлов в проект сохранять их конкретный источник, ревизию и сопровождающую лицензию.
